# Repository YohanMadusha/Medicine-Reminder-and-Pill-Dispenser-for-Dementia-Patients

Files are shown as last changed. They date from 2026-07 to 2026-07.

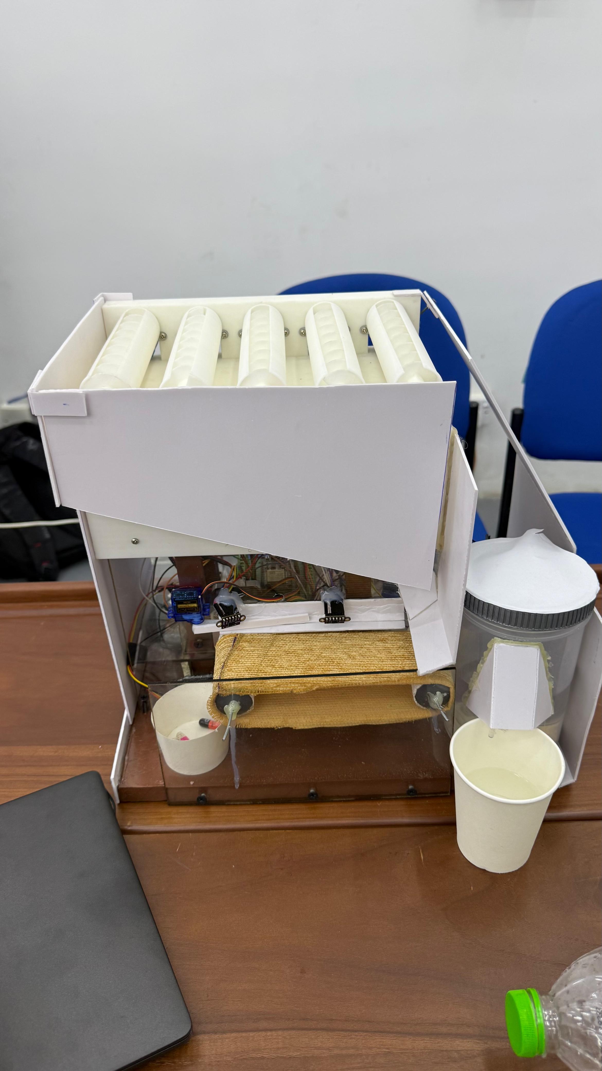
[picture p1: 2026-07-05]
Images/Prototype_photo.jpeg

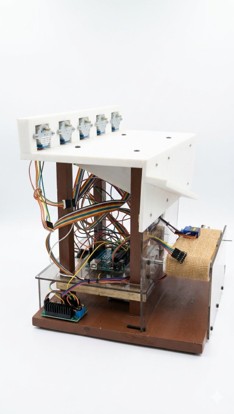
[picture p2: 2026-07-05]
Images/Picture1.jpg

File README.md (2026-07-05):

# Medicine-Reminder-and-Pill-Dispenser-for-Dementia-Patients
A smart mechatronics system for automated medicine dispensing and caregiver monitoring using ESP32.
# 🏥 Medicine Reminder and Pill Dispenser for Dementia Patients

Project Banner

## 📖 Overview

This project was developed as part of **ME2041 – Fundamentals of Mechatronics** at the **University of Moratuwa**.

The objective of this project is to assist dementia patients by automatically dispensing medicines according to a predefined schedule while allowing caregivers to monitor and manage the system remotely through a mobile application.

---

## 🎯 Features

- Automated medicine dispensing
- Five medicine compartments
- Conveyor belt transportation
- Automatic water dispensing
- Mobile application for caregivers
- Wi-Fi communication using ESP32
- Medicine pickup detection
- Water level monitoring
- Pill detection using ToF sensors

---

## ⚙ Hardware Components

- ESP32
- NEMA 17 Stepper Motor
- TB6600 Stepper Motor Driver
- 28BYJ-48 Stepper Motors
- A4988 Stepper Motor Driver
- Servo Motor
- VL53L0X Time-of-Flight Sensors
- IR Sensor
- Ultrasonic Sensor
- Water Pump
- 12V Power Supply
- Buck Converter
- Custom 3D Printed Parts

---

## 💻 Software

- Arduino IDE
- Android Studio
- SolidWorks

---

## 🏗 System Architecture

```
Android App
      │
      ▼
 Wi-Fi Communication
      │
      ▼
     ESP32
      │
 ┌──────────────┐
 │              │
 ▼              ▼
Motors      Sensors
 │              │
 ▼              ▼
Dispensing  Monitoring
```

---

## 📷 Prototype



---

## 📱 Mobile Application


---

## 👨‍💻 My Contribution

My primary contribution to this project was the design and implementation of the conveyor belt mechanism.

Responsibilities included:

- Selecting and integrating the NEMA 17 stepper motor.
- Driving the conveyor using the TB6600 stepper motor driver.
- Developing the conveyor control logic using the AccelStepper library.
- Testing and optimizing smooth pill transportation.

---

## 🚀 Engineering Challenges

One of the main challenges was the limited number of GPIO pins available on the ESP32.

To overcome this, we integrated the A4988 stepper motor driver, allowing the ESP32 to control stepper motors using only STEP and DIR signals instead of directly controlling all motor phases. This reduced GPIO usage while maintaining accurate motor control.

---

## 👥 Team

Developed by:

- Ishwar Kasthuriarachchi
- Pahan Pinibindu
- Anjana Chathumini
- S Naveendran
- Yohan Madusha

---

## 📄 License

MIT License

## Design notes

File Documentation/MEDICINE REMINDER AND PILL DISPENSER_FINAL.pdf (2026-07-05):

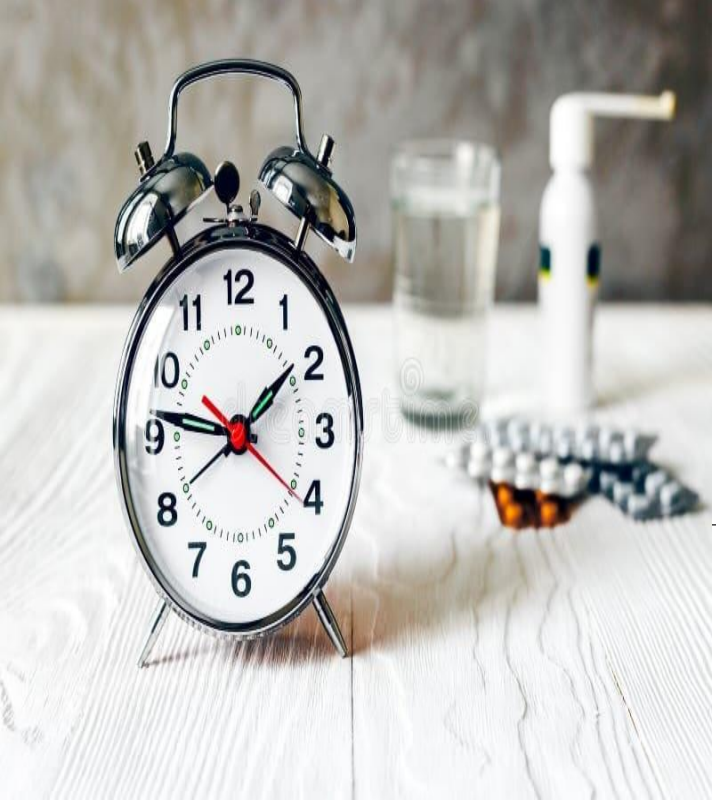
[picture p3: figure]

# MEDICINE REMINDER AND PILL DISPENSER

GROUP 07

# Our Team

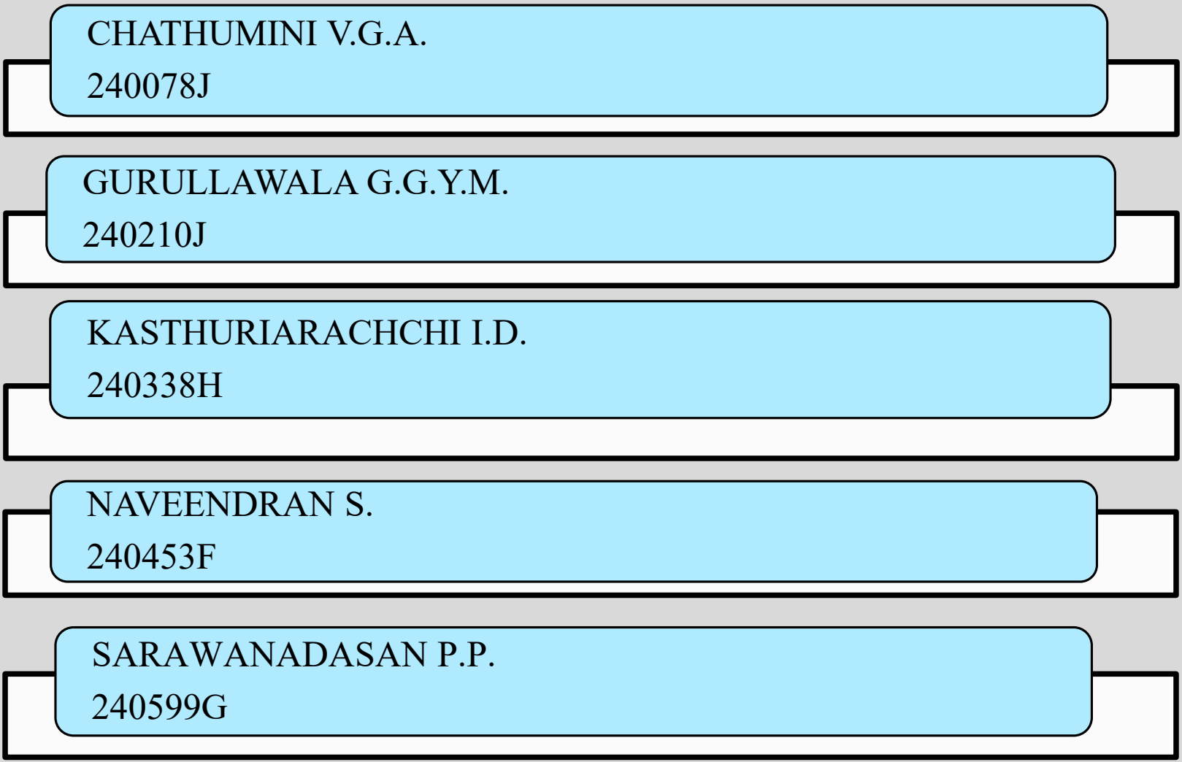
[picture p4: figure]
CHATHUMINI V.G.A.; GURULLAWALA G.G.Y.M.; KASTHURIARACHCHI I.D.; NAVEENDRAN S.; SARAWANADASAN P.P.

# Introduction

➢Patients with dementia often experience memory loss and difficulty following

medication schedules.

➢Missing or incorrect medication doses can lead to serious health complications.

➢Caregivers need an efficient way to monitor the regular medicine use of patient.

# What Makes Our System Different?

➢Automatically dispenses the exact prescribed number off pills using Archimedes’ screw

mechanism.

➢Supports up to five different medicine types within a single system.

➢Verifies pill dispensing using a VL53L0X sensor for improved dosage accuracy.

➢Provides automatic water dispensing together with medication.

➢Detects medicine collection using an IR sensor

➢Enables real-time caregiver monitoring through a mobile application.

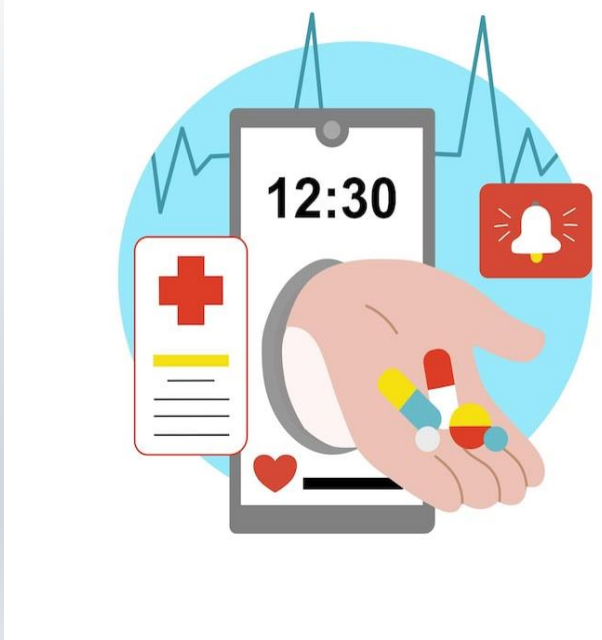
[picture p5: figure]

Our system integrates

medication reminders, pill

dispensing, water supply,

and caregiver monitoring

into a single smart healthcare

solution.

# Project Goal and Objectives

Develop a smart medicine reminder and automated pill dispensing system that improves medication adherence among dementia patients.

Goal:

➢Remind patients at scheduled medication times.

➢Dispense the correct number of pills automatically.

➢Supply drinking water together with the medication.

➢Monitor medicine collection by the patients.

➢Notify caregivers through a mobile application.

➢Reduce medication errors and missed doses.

Objectives:

➢Stores five different medicine types.

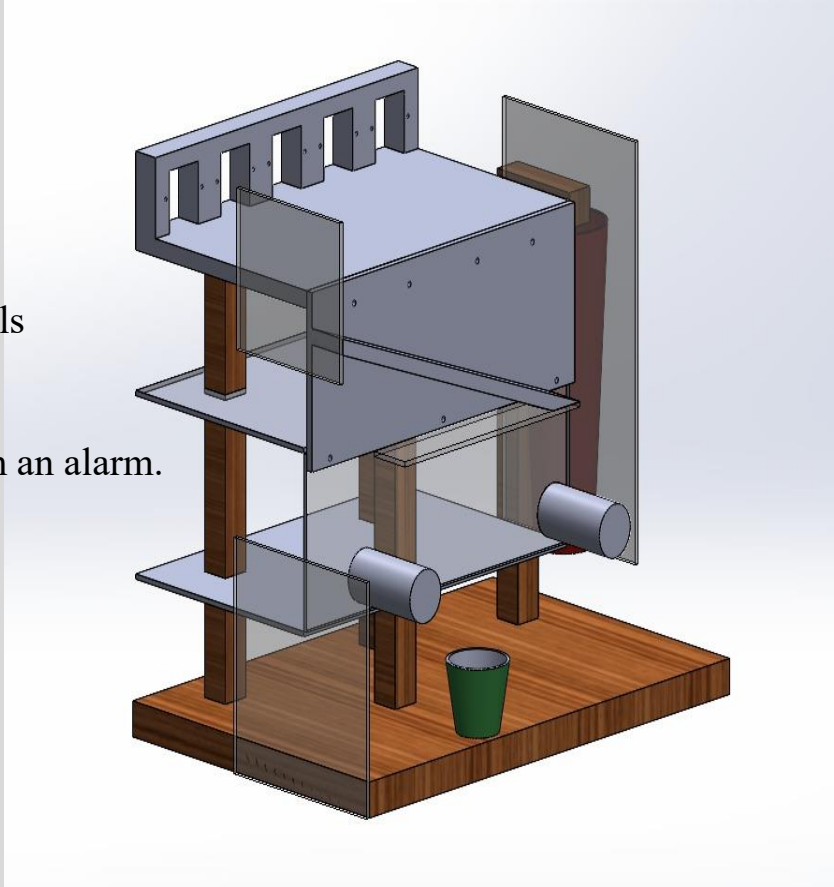
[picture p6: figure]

➢Dispenses the required number of pills

automatically.

➢Provides medicine reminders through an alarm.

➢Supplies water automatically.

➢Monitors medicine collection.

➢Sends notifications to caregivers.

# Our System

# Hardware Components

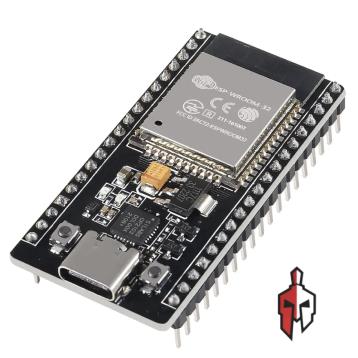
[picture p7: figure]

ESP32

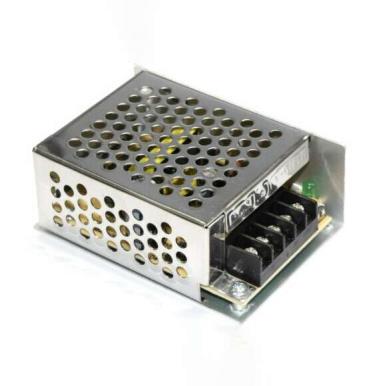
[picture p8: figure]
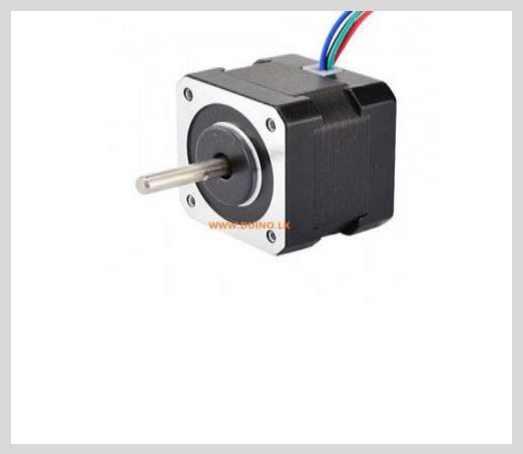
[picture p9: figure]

STEPPER MOTOR

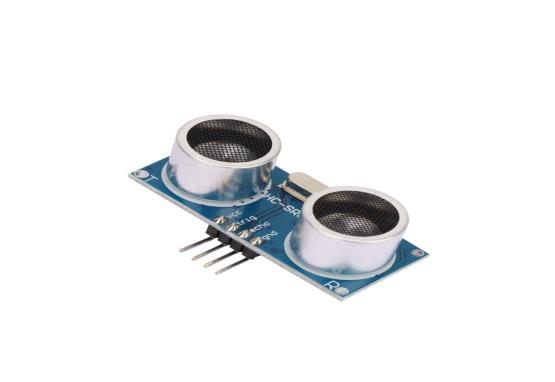
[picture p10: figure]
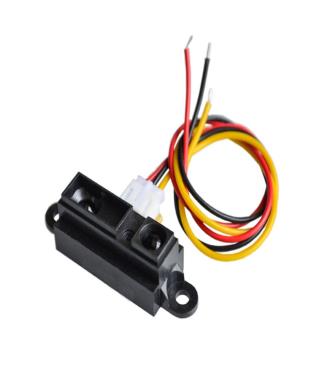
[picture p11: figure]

12V POWER ADAPTER | IR SENSOR | ULTRASONIC SENSOR

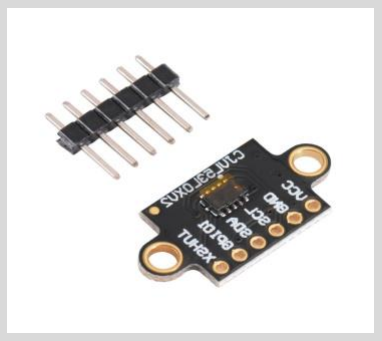
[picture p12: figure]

VL53L0X SENSOR

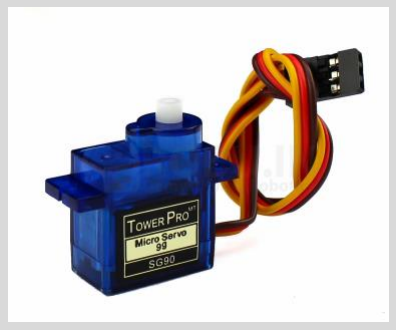
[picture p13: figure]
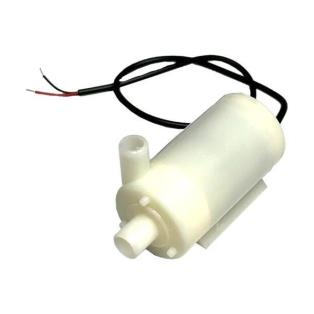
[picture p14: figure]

SERVO MOTOR | PUMP

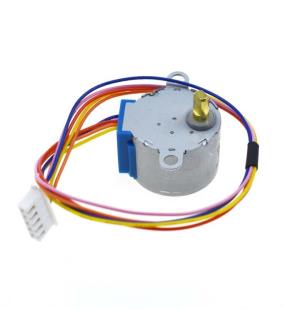
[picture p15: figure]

NEMA17 | 28BYJ-48
| STEPPER MOTOR

# Software Tools

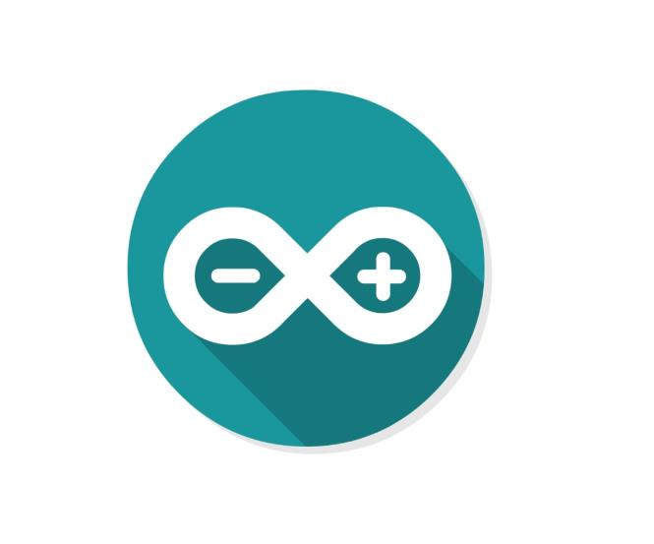
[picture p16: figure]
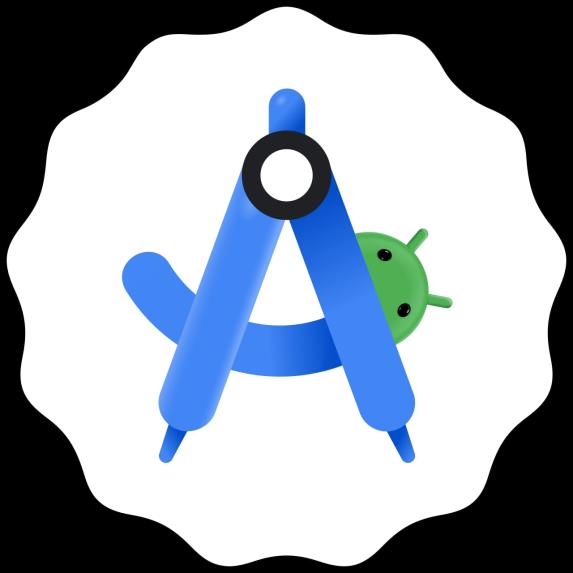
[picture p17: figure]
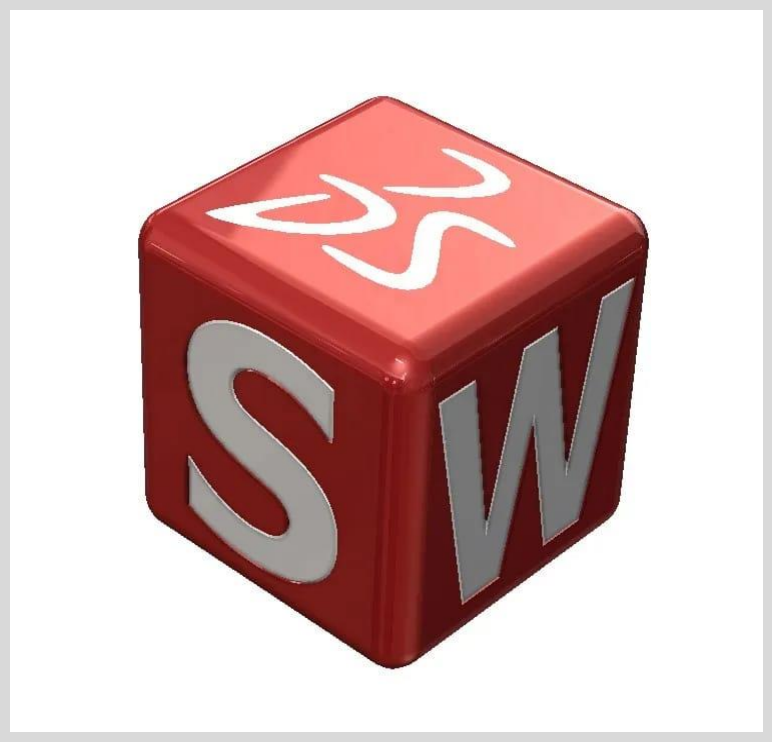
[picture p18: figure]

ARDUINO IDE | ANDROID STUDIO | SOLIDWORKS

# How It Works?

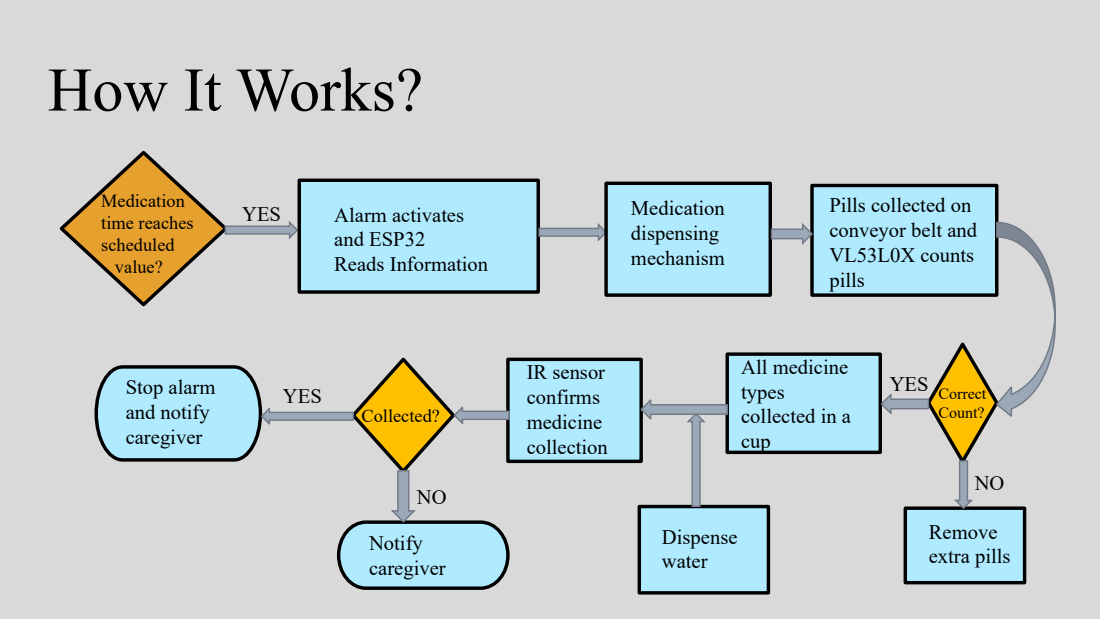
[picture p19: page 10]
Medication time reaches scheduled value?; Alarm activates and ESP32 Reads Information; Medication dispensing mechanism; Correct Count?; All medicine types collected in a cup; IR sensor confirms medicine collection; Collected?; Stop alarm and notify caregiver; Notify caregiver; Remove extra pills; Dispense water; YES

Pills collected on
conveyor belt and
VL53L0X counts
pills

# Pill Dispensing Mechanism Pill Dispensing

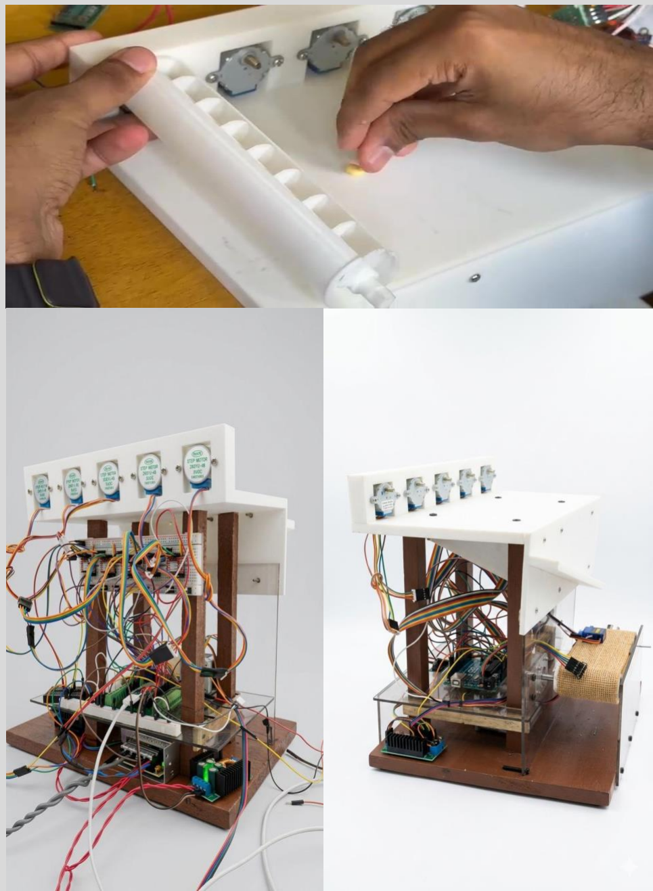
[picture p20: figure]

- Each medicine stored in a

separate container.

- The container uses an

Archimedes’ screw driven

by a stepper motor.

- The number of motor

rotations determines the

dosage.

Conveyor Belt

- The pills move into the

medicine cup after

dispensing.

- VL53L0X counts the

number of pills passing

through it.

- A servo motor removes

extra pills to continue the

medicine supply.

# Monitoring and Notification System

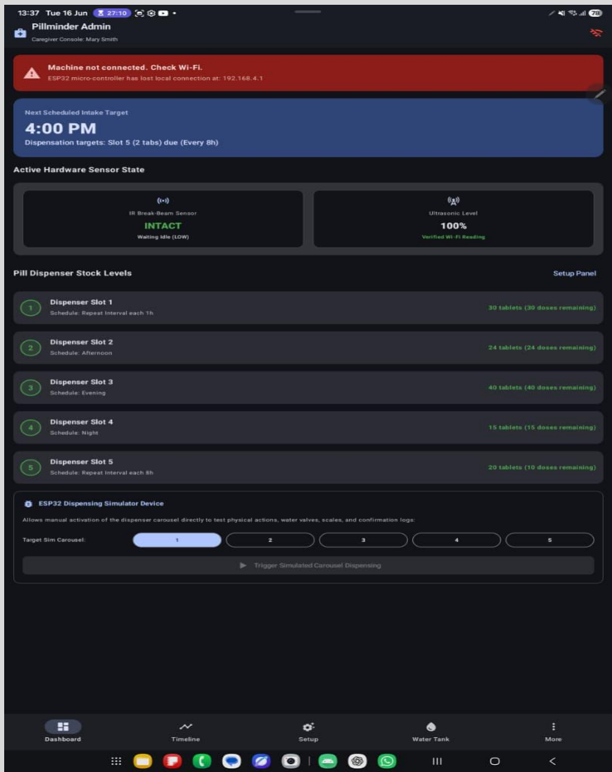
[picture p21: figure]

➢App-controlled dosage and notifications.

Notifications are sent to the caregiver:

- When medication time reaches the scheduled value.
- When it confirms the medicine collection by the IR

sensor.

- When tracking the medicine content in each

container after each dosage.

- When the water level of the tank reaches the

minimum value.

# Water Dispensing System

Components

- Water tank
- Water pump
- Ultrasonic sensor

Functions

- Dispense sufficient water automatically.
- Monitor the water level.
- Alert caregivers when the water level is low.

# Advantages

➢Improves medication adherence.

➢Reduces missed medication doses.

➢Supports dementia patients.

➢Provides accurate dosage dispensing.

➢Allows caregiver monitoring.

➢Reduces human errors.

➢Increases patients’ independence.

# Limitations

➢A limited number of pills can be contained in each spiral.

➢Supports only medicines compatible with the dispensing mechanism.

➢Requires a continuous power supply.

➢Limited to five medicine containers.

➢Cannot directly verify medicine consumption after collection.

# Future Improvements

- A pill sorting system to automatically load pills into the spirals.
- An efficient safety mechanism using image recognition.
- Expanded pill containers for more doses.
- Integration with hospital databases.
- Voice-assisted reminders.
- Battery backup system.

# Conclusion

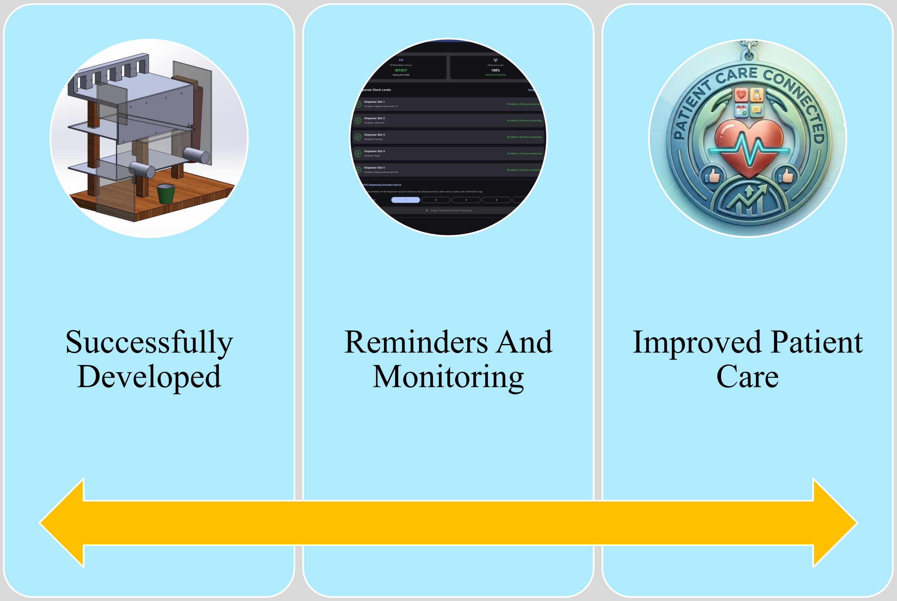
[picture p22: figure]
Successfully Developed; Reminders And Monitoring; Improved Patient Care

# Thank You!

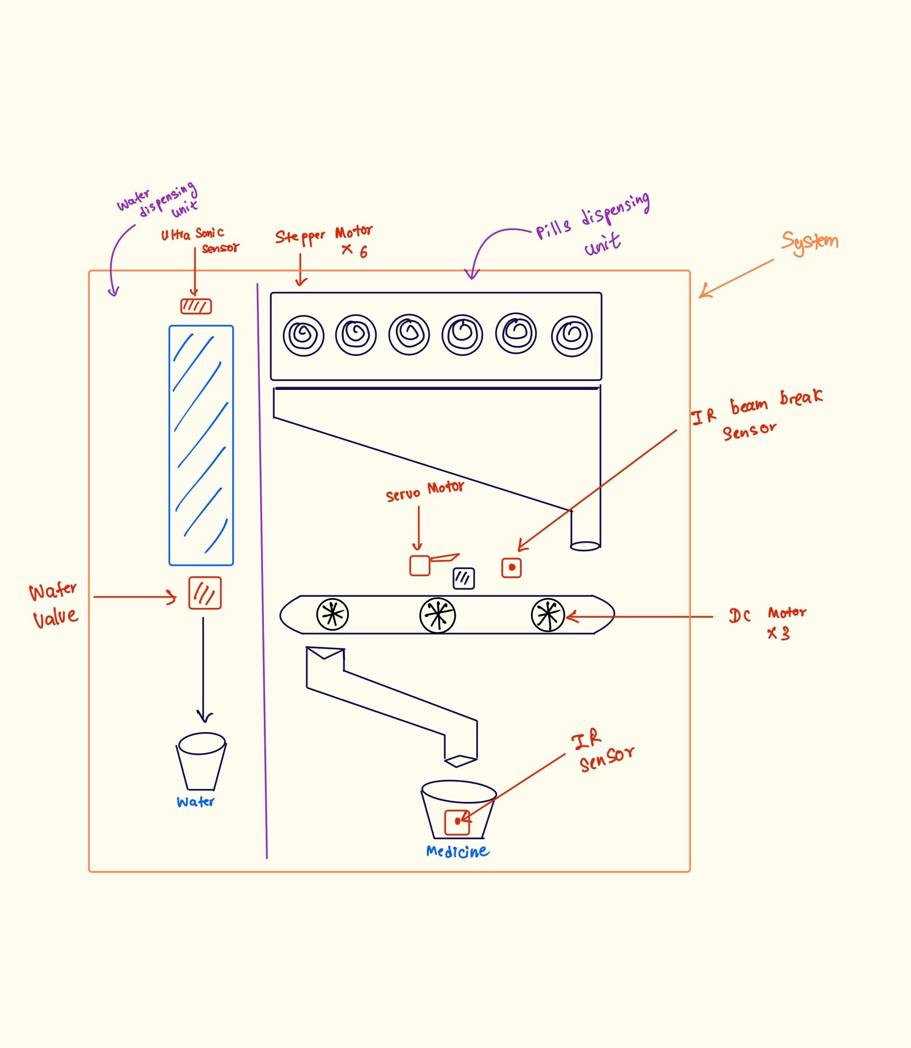
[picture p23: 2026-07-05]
Images/Proposed design.jpeg

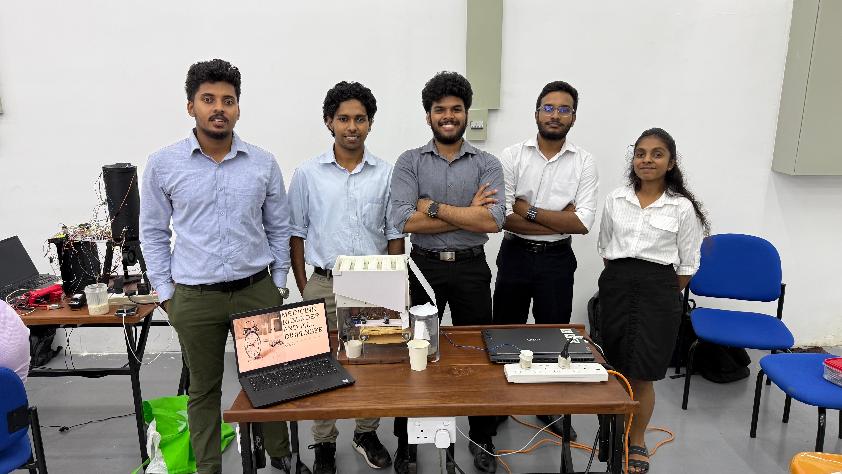
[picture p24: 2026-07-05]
Images/Group_photo.jpeg

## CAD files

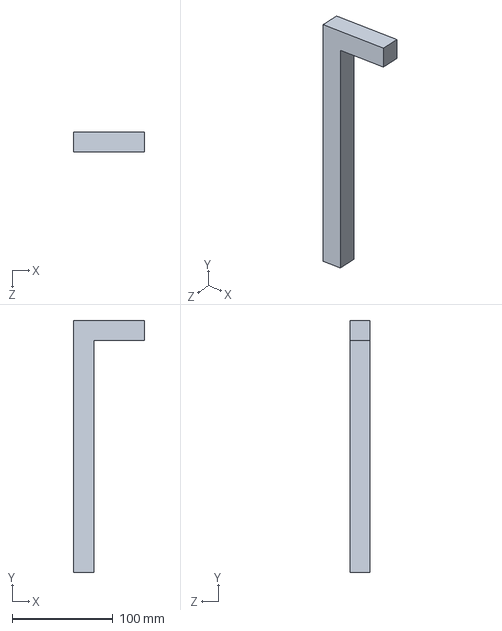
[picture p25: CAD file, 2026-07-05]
CAD/Parts(manufactureble)/Wood water container holder.SLDPRT
70.0 x 250.0 x 20.0 mm

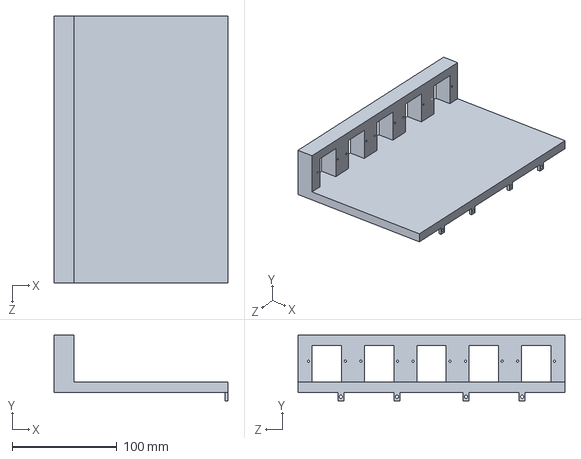
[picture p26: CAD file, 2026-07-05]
CAD/Solidworks/upper half v2-Boss-Extrude1.SLDPRT
166.2 x 63.0 x 255.2 mm

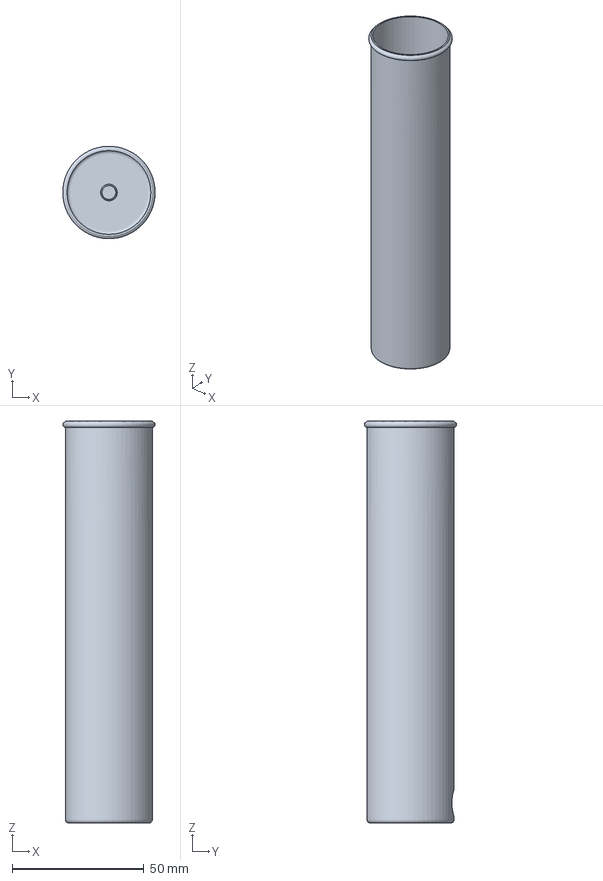
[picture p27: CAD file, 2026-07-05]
CAD/STL File/Outer_tube_v2.3mf
35.0 x 35.0 x 152.4 mm

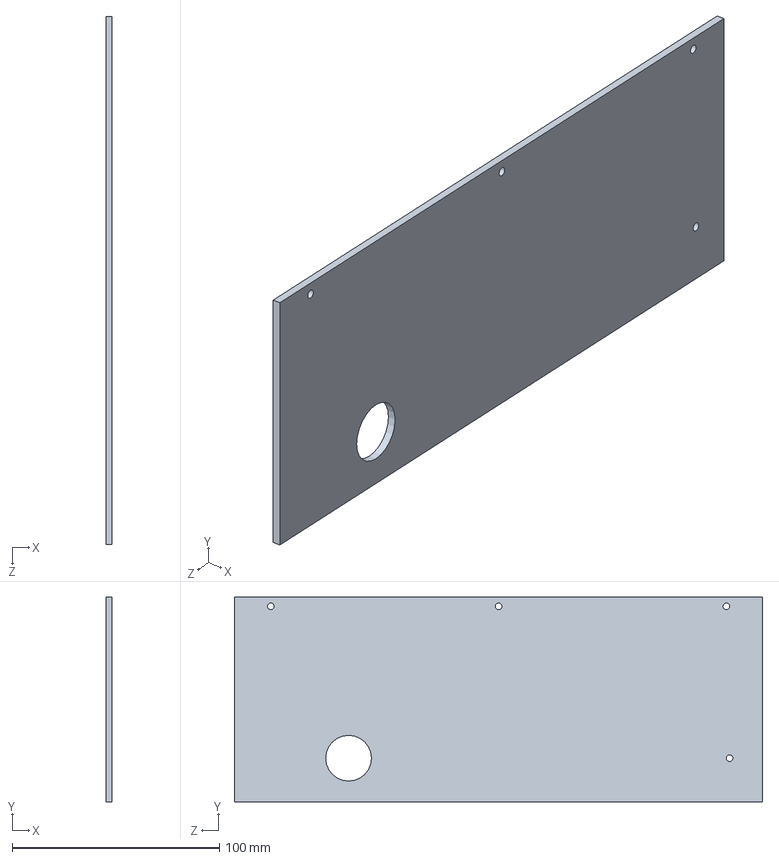
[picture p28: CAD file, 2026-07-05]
CAD/Parts(manufactureble)/behing the belt.SLDPRT
3.00 x 99.0 x 255.2 mm

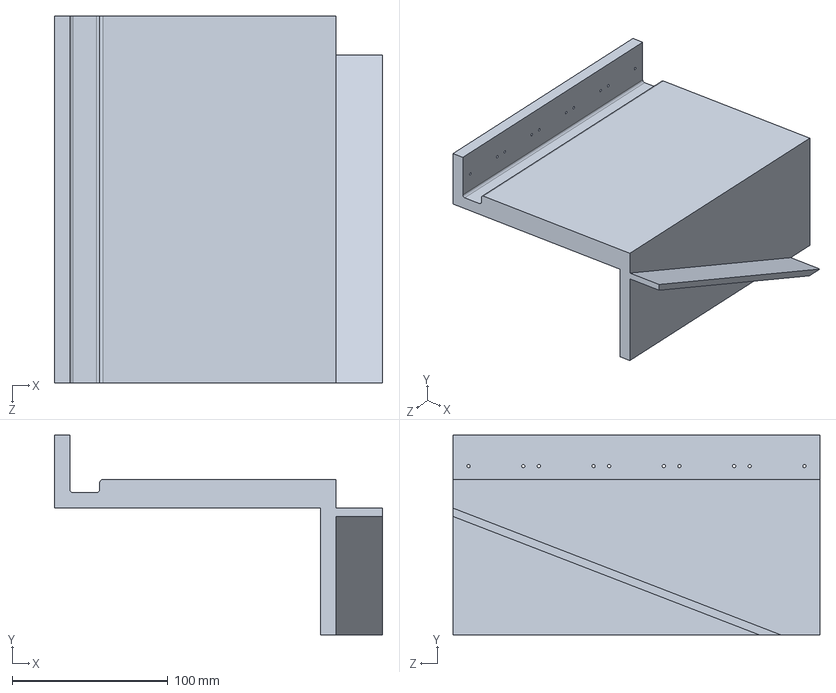
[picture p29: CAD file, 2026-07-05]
CAD/Solidworks/Upper half.SLDPRT
211.2 x 128.6 x 236.0 mm

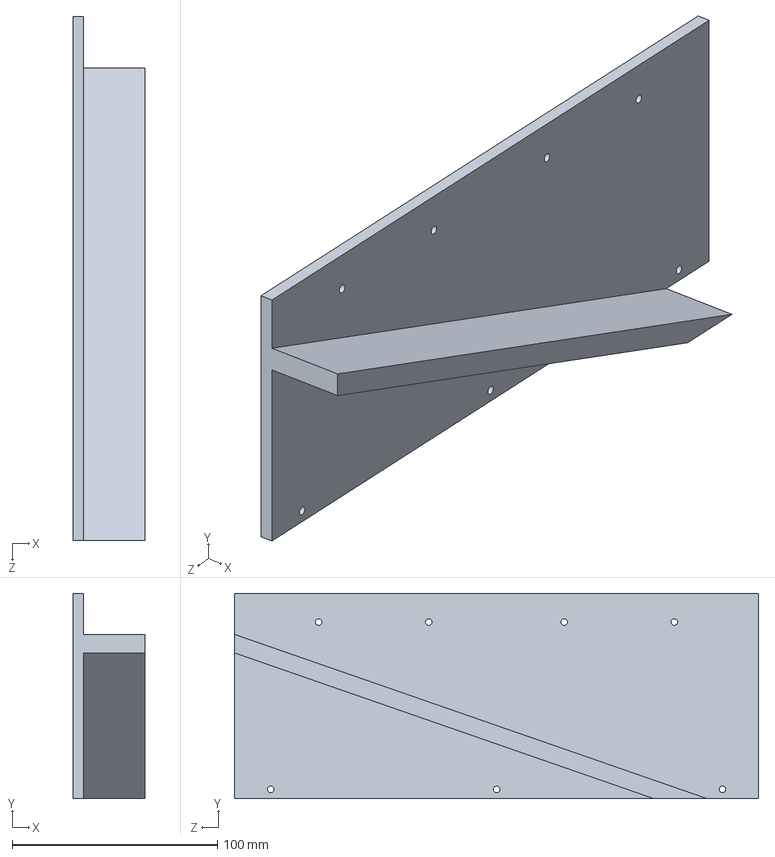
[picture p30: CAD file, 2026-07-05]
CAD/Solidworks/upper half v2-Boss-Extrude6.SLDPRT
35.0 x 100.0 x 255.2 mm

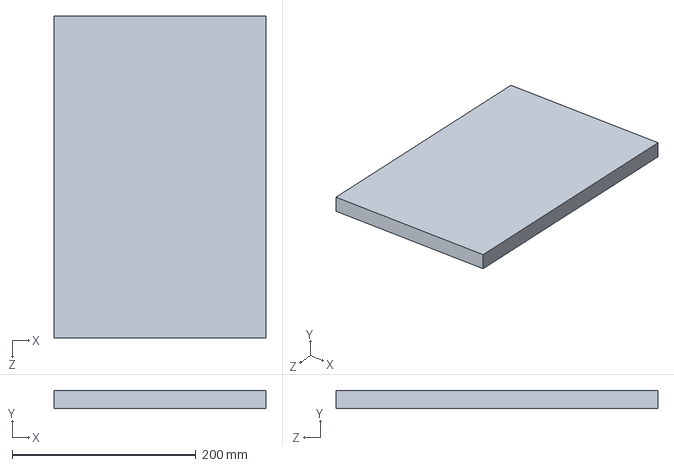
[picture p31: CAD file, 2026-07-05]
CAD/Parts(manufactureble)/Wood Base.SLDPRT
230.0 x 20.0 x 350.0 mm

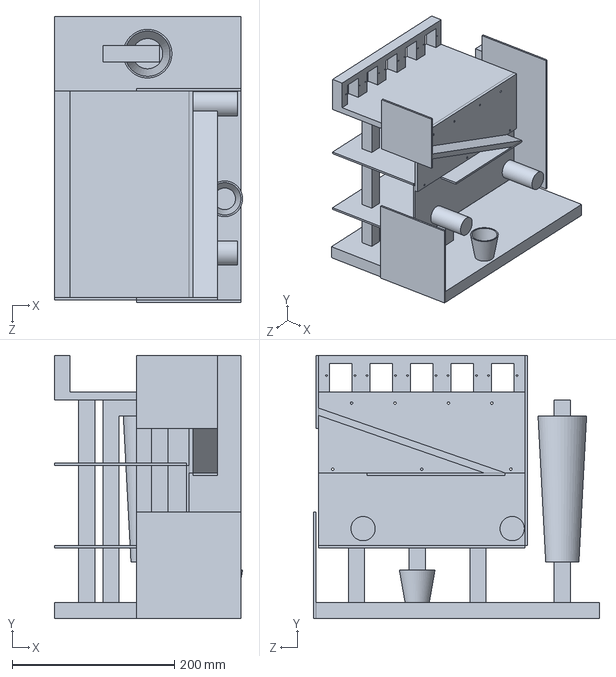
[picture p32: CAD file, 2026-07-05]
CAD/Solidworks/Final_design.SLDPRT
232.2 x 325.0 x 353.0 mm

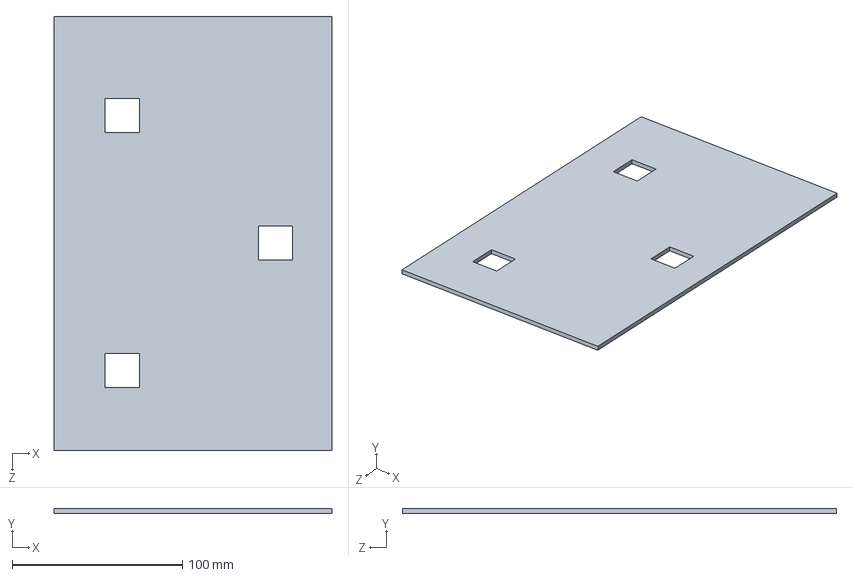
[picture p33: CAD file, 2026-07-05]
CAD/Parts(manufactureble)/Midlevel.SLDPRT
163.2 x 3.00 x 255.2 mm

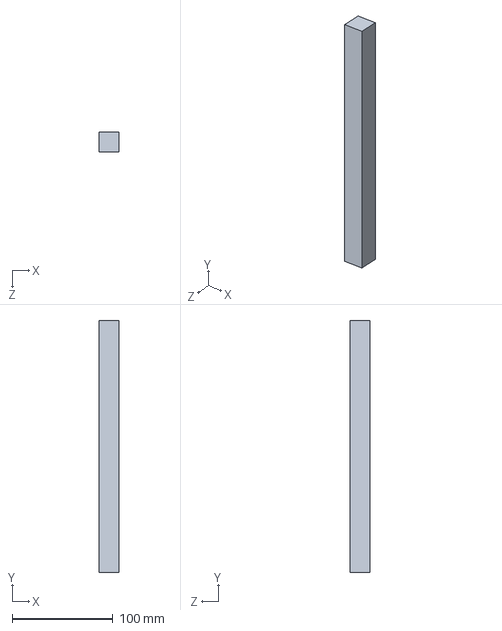
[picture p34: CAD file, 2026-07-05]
CAD/Parts(manufactureble)/Wood_pillar.SLDPRT
20.0 x 250.0 x 20.0 mm

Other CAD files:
CAD/Lasercutting/plate1.dwg
CAD/Lasercutting/plate2.dwg
CAD/STL File/Outer_tube_v3(final).3mf
CAD/Lasercutting/midplane.dwg
CAD/Parts(manufactureble)/Midlevel(V1).DWG
CAD/STL File/Outer_tube_v1.stl
CAD/Parts(manufactureble)/behing the belt.DWG

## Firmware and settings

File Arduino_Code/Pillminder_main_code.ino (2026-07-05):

#include <WiFi.h>
#include <WebServer.h>
#include <ArduinoJson.h>
#include <AccelStepper.h>
#include <Wire.h>
#include <Adafruit_VL53L0X.h>
#include <ESP32Servo.h>

const char* ssid = "Pillminder_ESP32";
const char* password = "12345678";
WebServer server(80);

bool enableSafetySystem = false; 

unsigned long syncEpoch = 0;
int timezoneOffsetSecs = 0;
unsigned long syncMillis = 0;

struct SlotSchedule {
  int slotNumber;
  int tabletsPerDose;
  String scheduleType; 
  String scheduleTimeStr; 
  unsigned long lastTriggeredEpoch; 
};

SlotSchedule schedules[5];

int slotQueue[10];
int pillQueue[10];
int queueHead = 0;
int queueTail = 0;

void pushToQueue(int slotIdx, int pills) {
  if ((queueTail + 1) % 10 != queueHead) {
    slotQueue[queueTail] = slotIdx;
    pillQueue[queueTail] = pills;
    queueTail = (queueTail + 1) % 10;
  }
}

bool popFromQueue(int &slotIdx, int &pills) {
  if (queueHead == queueTail) return false;
  slotIdx = slotQueue[queueHead];
  pills = pillQueue[queueHead];
  queueHead = (queueHead + 1) % 10;
  return true;
}

enum SystemState {
  IDLE,
  DISPENSING,        
  CLEARING_BELT,
  PAUSED_FOR_REJECT,  
  DISPENSING_WATER
};

SystemState currentState = IDLE;
String dispenserStatusStr = "IDLE"; 

int activeMotorIndex = -1;  
int targetPills = 0;       
int countedPills = 0;      

const long STEPS_PER_PILL = 3072; 

AccelStepper motor1(AccelStepper::DRIVER, 13, 14); 
AccelStepper motor2(AccelStepper::DRIVER, 27, 26); 
AccelStepper motor3(AccelStepper::DRIVER, 25, 33); 
AccelStepper motor4(AccelStepper::DRIVER, 32, 4);  
AccelStepper motor5(AccelStepper::DRIVER, 16, 17); 
AccelStepper* posMotors[] = {&motor1, &motor2, &motor3, &motor4, &motor5};

#define CONVEYOR_STEP_PIN 19                       
#define CONVEYOR_DIR_PIN 18                        
AccelStepper conveyor(AccelStepper::DRIVER, CONVEYOR_STEP_PIN, CONVEYOR_DIR_PIN);

const long CONVEYOR_STEPS_PER_REV = 800; 
const long CONVEYOR_STEPS_TO_CLEAR = 5 * CONVEYOR_STEPS_PER_REV; 

Servo rejectArm;
#define SERVO_PIN 12                               
const int ARM_REST_ANGLE = 90;     
const int ARM_REJECT_ANGLE = 0;    
bool isRejecting = false;
unsigned long rejectTriggerTime = 0;
const unsigned long SENSOR_TO_ARM_DELAY = 400; 
const unsigned long ARM_SWEEP_DURATION = 1000; 

#define PUMP_PIN 23                                
#define TRIG_PIN 2                                 
#define ECHO_PIN 34 

#define SENSOR1_XSHUT 5                            
#define SENSOR2_XSHUT 15                           
Adafruit_VL53L0X lox1 = Adafruit_VL53L0X();
Adafruit_VL53L0X lox2 = Adafruit_VL53L0X();
#define SENSOR1_ADDRESS 0x30
#define SENSOR2_ADDRESS 0x31

#define IR_CUP_PIN 35 
bool waitingForPickup = false; 
bool medicineTaken = false;    
bool manualIrBeamBroken = false; 

unsigned long lastWaterMonitorTime = 0;
const int WATER_MONITOR_INTERVAL = 2000; 
int calculatedWaterPercent = 100;
float filteredDistance = 100.0; 
const float EMA_ALPHA = 0.3;    
bool isFirstWaterReading = true; 
const unsigned long PUMP_RUN_TIME_MS = 10000; 
unsigned long pumpStartTime = 0;

unsigned long dispenseStartTime = 0;
const unsigned long MAX_DISPENSE_TIME_MS = 60000; 
bool dispenseTimedOut = false;

unsigned long lastToFCheck = 0;
const int ToF_INTERVAL = 20; 
int baselineDistance = 100; 
bool stage1Detected = false;
unsigned long stage1Time = 0;
const int CONFIRMATION_TIMEOUT = 300; 

unsigned long monitorStartTime = 0;
unsigned long monitorWindowDuration = 300000; 

unsigned long getLocalEpoch() {
  if (syncEpoch == 0) return 0;
  return syncEpoch + timezoneOffsetSecs + ((millis() - syncMillis) / 1000);
}

void setup() {
  Serial.begin(115200);

  WiFi.softAP(ssid, password);
  server.on("/sensor_data", HTTP_GET, handleSensorData);
  server.on("/sync_schedule", HTTP_POST, handleSyncSchedule);
  server.on("/trigger_demo_dose", HTTP_POST, handleTriggerDose);
  server.on("/simulate_beam_break", HTTP_POST, handleSimulateBeam);
  server.begin();

  pinMode(PUMP_PIN, INPUT); 
  pinMode(TRIG_PIN, OUTPUT);
  pinMode(ECHO_PIN, INPUT);
  pinMode(IR_CUP_PIN, INPUT);

  for(int i = 0; i < 5; i++) {
    posMotors[i]->setMaxSpeed(250.0);      
    posMotors[i]->setAcceleration(50.0);
    posMotors[i]->setMinPulseWidth(20); 
    schedules[i].slotNumber = i + 1;
    schedules[i].tabletsPerDose = 0;
    schedules[i].scheduleType = "FIXED_LABEL";
    schedules[i].scheduleTimeStr = "00:00";
    schedules[i].lastTriggeredEpoch = 0;
  }
  conveyor.setMaxSpeed(4000.0); 
  conveyor.setAcceleration(2000.0); 

  rejectArm.setPeriodHertz(50); 
  rejectArm.attach(SERVO_PIN, 500, 2400); 
  rejectArm.write(ARM_REST_ANGLE); 

  pinMode(SENSOR1_XSHUT, OUTPUT); pinMode(SENSOR2_XSHUT, OUTPUT);
  digitalWrite(SENSOR1_XSHUT, LOW); digitalWrite(SENSOR2_XSHUT, LOW); delay(10);
  digitalWrite(SENSOR1_XSHUT, HIGH); delay(10); lox1.begin(SENSOR1_ADDRESS);
  digitalWrite(SENSOR2_XSHUT, HIGH); delay(10); lox2.begin(SENSOR2_ADDRESS);

  Serial.println("System Ready.");
}

void loop() {
  server.handleClient();
  handleRejectServo(); 
  monitorCupPickup(); 
  

  switch (currentState) {
    case IDLE:
      if (millis() - lastWaterMonitorTime >= WATER_MONITOR_INTERVAL && !waitingForPickup) {
        lastWaterMonitorTime = millis();
        
        int dist = getWaterDistanceMM(); 
        
        
        if (dist != 999) { 
          if (isFirstWaterReading) {
            filteredDistance = dist; 
            isFirstWaterReading = false;
          } else {
            
            filteredDistance = (EMA_ALPHA * dist) + ((1.0 - EMA_ALPHA) * filteredDistance);
          }
          
          
          calculatedWaterPercent = constrain(map((int)filteredDistance, 180, 40, 0, 100), 0, 100);
          
          Serial.print("[WATER] Raw: "); Serial.print(dist); 
          Serial.print("mm | Filtered: "); Serial.print(filteredDistance); 
          Serial.print("mm | "); Serial.print(calculatedWaterPercent); Serial.println("%");
        } else {
          Serial.println("[WATER] 999 Error Spike Ignored");
        }

        
        VL53L0X_RangingMeasurementData_t m1, m2;
        lox1.rangingTest(&m1, false);
        lox2.rangingTest(&m2, false);
        Serial.print("[ToF1] "); Serial.print(m1.RangeMilliMeter);
        Serial.print("mm | [ToF2] "); Serial.println(m2.RangeMilliMeter);
      }
      if (queueHead != queueTail) {
        int sIdx, pCount;
        if (popFromQueue(sIdx, pCount)) {
          activeMotorIndex = sIdx;
          targetPills = pCount;
          posMotors[activeMotorIndex]->setCurrentPosition(0);
          posMotors[activeMotorIndex]->moveTo(targetPills * STEPS_PER_PILL);
          currentState = DISPENSING;
          dispenserStatusStr = "DISPENSING";
          dispenseStartTime = millis();
          dispenseTimedOut = false;
        }
      }
      break;

    case DISPENSING:
      posMotors[activeMotorIndex]->run();
      if (posMotors[activeMotorIndex]->distanceToGo() == 0 ||
          (millis() - dispenseStartTime > MAX_DISPENSE_TIME_MS)) {
        if (millis() - dispenseStartTime > MAX_DISPENSE_TIME_MS) {
          dispenseTimedOut = true;
          Serial.println("[WARN] Motor timeout! Possible jam on slot " + String(activeMotorIndex + 1));
          posMotors[activeMotorIndex]->stop();
        }
        conveyor.setCurrentPosition(0);
        conveyor.moveTo(CONVEYOR_STEPS_TO_CLEAR);
        currentState = CLEARING_BELT;
        dispenserStatusStr = "CLEARING_BELT";
      }
      break;

    case CLEARING_BELT:
      conveyor.run(); 
      if (conveyor.distanceToGo() == 0) {
        if (queueHead != queueTail) {
          int sIdx, pCount;
          popFromQueue(sIdx, pCount);
          activeMotorIndex = sIdx;
          targetPills = pCount;
          posMotors[activeMotorIndex]->setCurrentPosition(0);
          posMotors[activeMotorIndex]->moveTo(targetPills * STEPS_PER_PILL);
          currentState = DISPENSING;
          dispenserStatusStr = "DISPENSING";
          dispenseStartTime = millis();
          dispenseTimedOut = false;
        } else {
          pinMode(PUMP_PIN, OUTPUT); digitalWrite(PUMP_PIN, LOW); 
          pumpStartTime = millis(); 
          currentState = DISPENSING_WATER;
          dispenserStatusStr = "DISPENSING_WATER";
        }
      }
      break;

    case DISPENSING_WATER:
      if (millis() - pumpStartTime >= PUMP_RUN_TIME_MS) {
        pinMode(PUMP_PIN, INPUT);
        currentState = IDLE;
        
        waitingForPickup = true;
        monitorStartTime = millis();
        dispenserStatusStr = "MONITORING";
        manualIrBeamBroken = false;  
        Serial.println("[STATE] Pump done. Monitoring for cup pickup...");
      }
      break;
  }
}

void handleSensorData() {
  StaticJsonDocument<200> doc;
  doc["weightGrams"] = 0.0;
  doc["waterLevelPercent"] = calculatedWaterPercent;
  
  bool realIr = (digitalRead(IR_CUP_PIN) == HIGH);
  doc["irBeamBroken"] = realIr || manualIrBeamBroken;
  doc["doseStatus"] = dispenserStatusStr;

  unsigned long currentLocalEpoch = getLocalEpoch();
  int currentHour = (currentLocalEpoch % 86400) / 3600;
  int currentMin = ((currentLocalEpoch % 86400) % 3600) / 60;
  char timeBuf[10];
  sprintf(timeBuf, "%02d:%02d", currentHour, currentMin);
  doc["espTime"] = timeBuf;

  String response;
  serializeJson(doc, response);
  server.send(200, "application/json", response);
}

void handleTriggerDose() {
  
  if (currentState != IDLE) {
    server.send(409, "application/json", "{\"status\":\"busy\",\"message\":\"System is currently dispensing. Wait for completion.\"}");
    return;
  }

  if (server.hasArg("plain") == false) {
    server.send(400, "text/plain", "Body not received");
    return;
  }
  StaticJsonDocument<512> doc;
  DeserializationError error = deserializeJson(doc, server.arg("plain"));
  if (error) {
    server.send(400, "text/plain", "Invalid JSON");
    return;
  }
  
  queueHead = 0; 
  queueTail = 0;

  JsonArray slotsArray = doc["slots"].as<JsonArray>();
  if (doc.containsKey("monitorWindowMs")) {
    monitorWindowDuration = doc["monitorWindowMs"].as<unsigned long>();
  }

  for (JsonObject slotObj : slotsArray) {
    int slotIndex = slotObj["slotNumber"].as<int>() - 1;
    if (slotIndex >= 0 && slotIndex < 5) {
      int pills = slotObj["pills"].as<int>();
      if (pills <= 0) pills = 1; 
      pushToQueue(slotIndex, pills);
    }
  }
  
  server.send(200, "application/json", "{\"status\":\"success\"}");
}

void handleSyncSchedule() {
  if (server.hasArg("plain") == false) {
    server.send(400, "text/plain", "Body not received");
    return;
  }
  StaticJsonDocument<1024> doc;
  DeserializationError error = deserializeJson(doc, server.arg("plain"));
  if (error) {
    server.send(400, "text/plain", "Invalid JSON");
    return;
  }
  
  syncEpoch = doc["timestamp"].as<unsigned long>();
  timezoneOffsetSecs = doc["timezoneOffsetSeconds"].as<int>();
  syncMillis = millis();

  JsonArray slotsArray = doc["slots"].as<JsonArray>();
  for (JsonObject slotObj : slotsArray) {
    int slotNum = slotObj["slotNumber"].as<int>();
    if (slotNum >= 1 && slotNum <= 5) {
      int idx = slotNum - 1;
      schedules[idx].tabletsPerDose = slotObj["tabletsPerDose"].as<int>();
      schedules[idx].scheduleType = slotObj["scheduleType"].as<String>();
      schedules[idx].scheduleTimeStr = slotObj["scheduleTimeStr"].as<String>();
    }
  }
  
  server.send(200, "application/json", "{\"status\":\"synced\"}");
}

void handleSimulateBeam() {
  manualIrBeamBroken = true;
  if (waitingForPickup) {
    medicineTaken = true;
    waitingForPickup = false;
    dispenserStatusStr = "TAKEN";
  }
  server.send(200, "application/json", "{\"status\":\"beam_broken\"}");
}

void checkAutonomousSchedule() {
  if (syncEpoch == 0 || currentState != IDLE) return;

  unsigned long currentLocalEpoch = getLocalEpoch();
  int currentHour = (currentLocalEpoch % 86400) / 3600;
  int currentMin = ((currentLocalEpoch % 86400) % 3600) / 60;

  for (int i = 0; i < 5; i++) {
    if (schedules[i].tabletsPerDose <= 0) continue;

    if (currentLocalEpoch - schedules[i].lastTriggeredEpoch < 60) continue;

    bool shouldTrigger = false;

    if (schedules[i].scheduleType == "FIXED_LABEL") {
      int cIndex = schedules[i].scheduleTimeStr.indexOf(':');
      if (cIndex > 0) {
        int tHour = schedules[i].scheduleTimeStr.substring(0, cIndex).toInt();
        int tMin = schedules[i].scheduleTimeStr.substring(cIndex + 1).toInt();
        
        int targetMinOfDay = tHour * 60 + tMin;
        int currentMinOfDay = currentHour * 60 + currentMin;
        int diff = currentMinOfDay - targetMinOfDay;
        if (diff >= 0 && diff <= 2) {
          shouldTrigger = true;
        }
      }
    } else if (schedules[i].scheduleType == "INTERVAL") {
      int intervalHours = schedules[i].scheduleTimeStr.toInt();
      if (intervalHours > 0) {
        
        if (currentHour % intervalHours == 0 && currentMin <= 2) {
          shouldTrigger = true;
        }
      }
    }

    if (shouldTrigger) {
      schedules[i].lastTriggeredEpoch = currentLocalEpoch;
      pushToQueue(i, schedules[i].tabletsPerDose);
    }
  }
}

void monitorCupPickup() {
  if (waitingForPickup) {
    bool isCupMissing = (digitalRead(IR_CUP_PIN) == HIGH) || manualIrBeamBroken;

    if (isCupMissing) {
      medicineTaken = true;        
      waitingForPickup = false;   
      dispenserStatusStr = "TAKEN";
      Serial.println(">>> SENSOR TRIGGERED: Medicine TAKEN. <<<");
    } else {
      if (millis() - monitorStartTime > monitorWindowDuration) {
        waitingForPickup = false;
        dispenserStatusStr = "NOT_TAKEN";
        Serial.println(">>> TIMEOUT: Medicine MISSED. <<<");
      }
    }
  } else if (dispenserStatusStr == "TAKEN" || dispenserStatusStr == "NOT_TAKEN") {
    if (millis() - monitorStartTime > (monitorWindowDuration + 5000)) {
       dispenserStatusStr = "IDLE";
       manualIrBeamBroken = false;
    }
  }
}

int getWaterDistanceMM() {
  int readings[3];
  int validCount = 0;

  for (int i = 0; i < 3; i++) {
    digitalWrite(TRIG_PIN, LOW);
    delayMicroseconds(2);
    digitalWrite(TRIG_PIN, HIGH);
    delayMicroseconds(10);
    digitalWrite(TRIG_PIN, LOW);
    
    long duration = pulseIn(ECHO_PIN, HIGH, 30000); 
    int d = (duration * 0.343) / 2;
    
    if (duration > 0 && d > 0 && d < 400) { 
      readings[validCount] = d;
      validCount++;
    }
    delay(10); 
  }

  
  if (validCount == 0) return 999; 

  
  if (validCount >= 2) {
    if (readings[0] > readings[1]) { int temp = readings[0]; readings[0] = readings[1]; readings[1] = temp; }
    if (validCount == 3) {
      if (readings[1] > readings[2]) { int temp = readings[1]; readings[1] = readings[2]; readings[2] = temp; }
      if (readings[0] > readings[1]) { int temp = readings[0]; readings[0] = readings[1]; readings[1] = temp; }
      return readings[1]; 
    }
  }
  return readings[0]; 
}

void triggerRejectSequence() {
  isRejecting = true;
  rejectTriggerTime = millis();
}

void handleRejectServo() {
  if (!isRejecting) return;
  unsigned long timeSinceTrigger = millis() - rejectTriggerTime;
  if (timeSinceTrigger >= SENSOR_TO_ARM_DELAY && timeSinceTrigger < (SENSOR_TO_ARM_DELAY + ARM_SWEEP_DURATION)) {
    rejectArm.write(ARM_REJECT_ANGLE); 
  } else if (timeSinceTrigger >= (SENSOR_TO_ARM_DELAY + ARM_SWEEP_DURATION)) {
    rejectArm.write(ARM_REST_ANGLE);
    isRejecting = false;
  }
}

bool checkPillDrop() {
  VL53L0X_RangingMeasurementData_t measure;
  if (!stage1Detected) {
    lox1.rangingTest(&measure, false);
    if (measure.RangeStatus != 4 && measure.RangeMilliMeter < (baselineDistance - 20)) {
      stage1Detected = true;       
      stage1Time = millis();       
    }
  } else {
    lox2.rangingTest(&measure, false);
    if (measure.RangeStatus != 4 && measure.RangeMilliMeter < (baselineDistance - 20)) {
      stage1Detected = false; 
      return true; 
    }
    if (millis() - stage1Time > CONFIRMATION_TIMEOUT) {
      stage1Detected = false; 
    }
  }
  return false;
}

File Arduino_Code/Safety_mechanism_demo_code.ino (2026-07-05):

#include <Wire.h>
#include <Adafruit_VL53L0X.h>
#include <ESP32Servo.h>

#define SENSOR1_XSHUT 5   
#define SENSOR2_XSHUT 15  
#define SERVO_PIN 12      

Adafruit_VL53L0X lox1 = Adafruit_VL53L0X();
Adafruit_VL53L0X lox2 = Adafruit_VL53L0X();
#define SENSOR1_ADDRESS 0x30
#define SENSOR2_ADDRESS 0x31

Servo rejectArm;
const int ARM_REST_ANGLE = 45;    
const int ARM_REJECT_ANGLE = 90;  

int intendedPills = 0;
int countedPills = 0;
bool isSessionActive = false;

bool pillPassedToF1 = false; 

unsigned long lastPrintTime = 0;
const unsigned long PRINT_INTERVAL = 200;

void setup() {
  Serial.begin(115200);
  while (!Serial) { delay(10); }

  rejectArm.setPeriodHertz(50);  
  rejectArm.attach(SERVO_PIN, 500, 2400);  
  rejectArm.write(ARM_REST_ANGLE);  

  Wire.begin();
  pinMode(SENSOR1_XSHUT, OUTPUT); 
  pinMode(SENSOR2_XSHUT, OUTPUT);
  
  digitalWrite(SENSOR1_XSHUT, LOW); 
  digitalWrite(SENSOR2_XSHUT, LOW); 
  delay(10);
  
  digitalWrite(SENSOR1_XSHUT, HIGH); 
  delay(10); 
  if (!lox1.begin(SENSOR1_ADDRESS)) {
    Serial.println("[ERROR] Failed to find VL53L0X #1!");
    while (1);
  }

  digitalWrite(SENSOR2_XSHUT, HIGH); 
  delay(10); 
  if (!lox2.begin(SENSOR2_ADDRESS)) {
    Serial.println("[ERROR] Failed to find VL53L0X #2!");
    while (1);
  }

  Serial.println("\n=== Sequential Pill Counter System Initialized ===");
  Serial.println("Servo holding at rest (45°).");
  Serial.println("Please enter the number of intended pills in the Serial Monitor:");
}

void loop() {
  if (Serial.available() > 0) {
    int input = Serial.parseInt();
    if (input > 0) {
      intendedPills = input;
      countedPills = 0;
      isSessionActive = true;
      pillPassedToF1 = false;
      rejectArm.write(ARM_REST_ANGLE); 
      
      Serial.print("\n>>> TARGET SET: Expecting ");
      Serial.print(intendedPills);
      Serial.println(" pill(s). Start dropping pills now.");
    }
    while(Serial.available() > 0) { Serial.read(); } 
  }

  if (isSessionActive) {
    VL53L0X_RangingMeasurementData_t m1, m2;
    lox1.rangingTest(&m1, false);
    lox2.rangingTest(&m2, false);

    int dist1 = (m1.RangeStatus != 4) ? m1.RangeMilliMeter : 999;
    int dist2 = (m2.RangeStatus != 4) ? m2.RangeMilliMeter : 999;

    if (!pillPassedToF1 && dist1 < 40) {
      pillPassedToF1 = true; 
      Serial.println("\n[LOGIC] Pill passed ToF1 -> 1st condition met.");
    }

    if (pillPassedToF1 && dist2 < 60) {
      countedPills++; 
      pillPassedToF1 = false; 
      
      Serial.print("[LOGIC] Pill passed ToF2 -> Count = ");
      Serial.println(countedPills);

      if (countedPills > intendedPills) {
        rejectArm.write(ARM_REJECT_ANGLE); 
        Serial.print(" [OVERCOUNT] ");
        Serial.print(countedPills);
        Serial.print(" > ");
        Serial.print(intendedPills);
        Serial.println(" (Target Exceeded)! Servo motor rotates to 90°.");
        isSessionActive = false; 
      }
    }

    if (isSessionActive) {
      rejectArm.write(ARM_REST_ANGLE);
    }

    if (millis() - lastPrintTime >= PRINT_INTERVAL) {
      lastPrintTime = millis();
      Serial.print("ToF1: "); Serial.print(dist1);
      Serial.print("mm | ToF2: "); Serial.print(dist2);
      Serial.print("mm | Gate Status: "); Serial.print(pillPassedToF1 ? "ARMED" : "WAITING");
      Serial.print(" | Count: "); Serial.print(countedPills);
      Serial.print("/"); Serial.println(intendedPills);
    }
  }
}
